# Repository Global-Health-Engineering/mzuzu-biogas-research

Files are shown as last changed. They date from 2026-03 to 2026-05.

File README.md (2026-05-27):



# Solar Sludge Pasteurization Control System

This repository contains the engineering files, firmware, and analysis scripts for a solar-powered sludge pasteurization system deployed in Mzuzu, Malawi. The system automates the thermal treatment of anaerobic digester effluent to ensure safe, pathogen-free discharge.

## Electronics Design
Hardware design files developed in KiCad.
- solar_pasteurization_controller: The main PCB project including schematics (mcu, power, solar_charger, actuators), PCB layout, and 3D models.
- simulations: SPICE simulations for the power switching circuitry.

## Microcontroller Software
Primary system firmware built using Zephyr RTOS.
- nucleo_l432kc_program_ert_algo: The production firmware implementing the retention time estimation algorithm. Needs to be tested.
- LoRa_TX / LoRa_RX: Simple LoRa scripts for testing. LoRa RX runs on the STM32L432KC eval-board that is connected to the research hut laptop.
- nucleo_l432kc_program_no_rtc: The production firmware implementing the threshold-based control logic.

## Arduino Software
Software that runs on the 2 Arduinos inside the Mzuzu research hut.
- luca_electronics: The software that runs on the microcontroller that's part of Luca Jakobs' biogas pasteurizer system.
- shared_plumbing_electronics: This pertains to the infrastructure electronics.

## Measurements
Data processing and experimental analysis scripts (Python).
- Heat Exchanger Efficiency: Scripts to calculate the h values and thermal efficiency from raw .csv data.
- espinosa_d_values: Logarithmic fit scripts for pathogen inactivation kinetics with data points taken from Deniz Cinar's paper.
- solcast_data_analysis: Analysis of solar irradiance data for the Mzuzu region.
- data_analysis_scripts: Contains the Python scripts for analyzing the .csv data files that can be found in the mzuzu-biogas-research git repo. That repo contains up-to-date data from the research site. 

## PC Software
High-level data handling and parsing for the research hut PC.
- nucleo_parser: Parses the USB packets sent by the LoRa RX microcontroller.
- edb_parser: Parses the USB packets sent by the infrastructure microcontroller. This is called *edb_parser* because it evolved from a simple automation of the EDB (effluent distribution) box.
- lj_parser: Parses the USB packets sent by the biogas pasteurization system microcontroller

For questions, please contact me through:
rcppolat@gmail.com

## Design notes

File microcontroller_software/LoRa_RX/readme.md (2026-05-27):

This is the piece of code that runs on the LoRa board located inside the research hut.
It receives LoRa packets from the solar heater, parses them, and sends them as a 
serial packet to the research hut computer over USB.

This is a Zephyr project.

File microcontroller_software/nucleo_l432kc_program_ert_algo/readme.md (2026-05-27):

This is the code that runs on the solar heater (ert calculating algorithm).
You need a local Zephyr RTOS installation to build and flash this code.

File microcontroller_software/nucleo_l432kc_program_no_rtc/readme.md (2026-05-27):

This is the code that runs on the solar heater (naive algorithm).
You need a local Zephyr RTOS installation to build and flash this code.

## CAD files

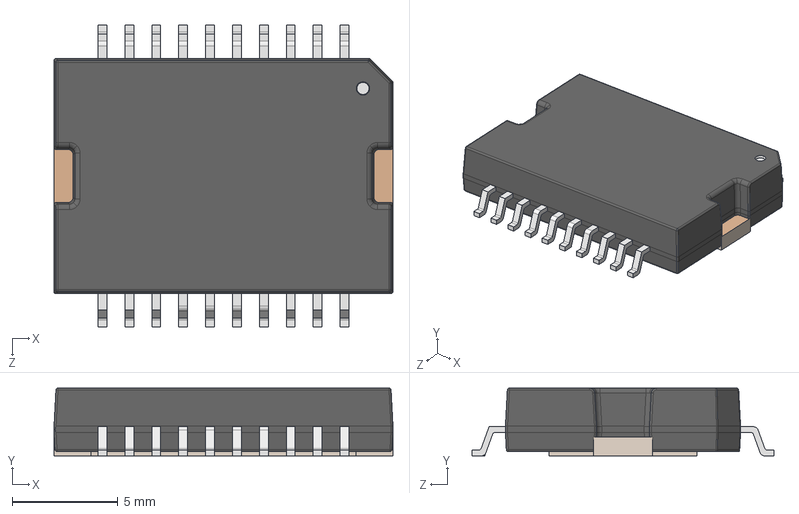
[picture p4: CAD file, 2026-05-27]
Electronics Design/solar_pasteurization_controller/User Library-HSOP_20pin_IC-MC33886PVW.step
16.0 x 3.20 x 14.2 mm

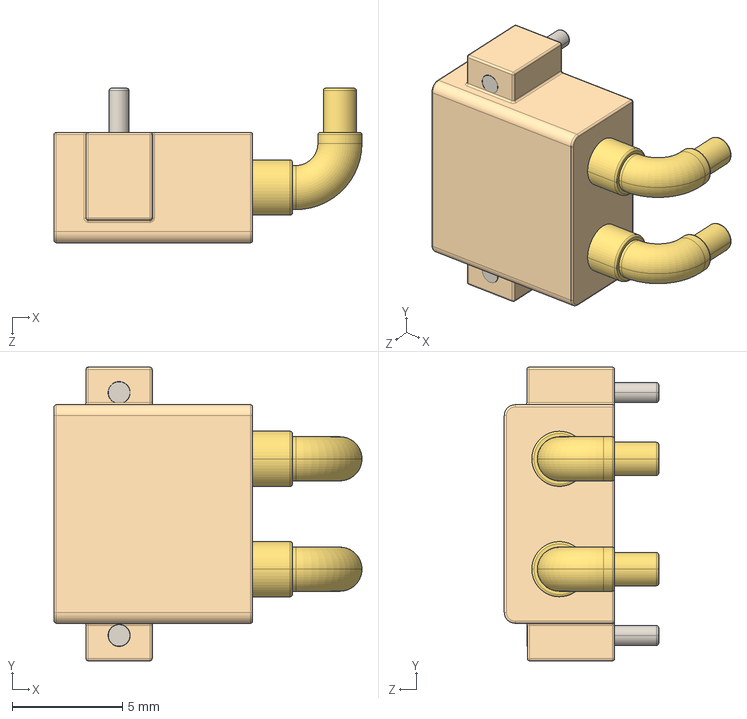
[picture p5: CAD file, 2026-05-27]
Electronics Design/solar_pasteurization_controller/User Library-XT30PW-M.step
13.9 x 13.3 x 7.00 mm

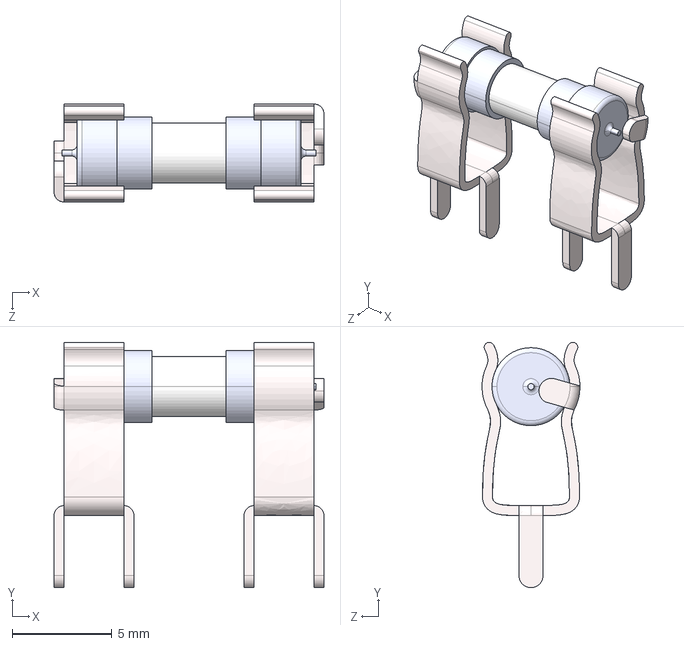
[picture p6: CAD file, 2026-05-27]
Electronics Design/solar_pasteurization_controller/Fuse Holder PCB.STEP
13.5 x 12.3 x 4.90 mm

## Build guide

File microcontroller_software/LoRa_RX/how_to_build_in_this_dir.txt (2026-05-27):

source ~/zephyrproject/.venv/bin/activate
source ~/zephyrproject/zephyr/zephyr-env.sh

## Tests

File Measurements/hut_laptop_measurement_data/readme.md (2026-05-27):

# Research Hut Data Logs

The research computer in the Mzuzu Research Hut records data from two independent microcontroller systems:

1. **Solar heater telemetry** (received over LoRa)
2. **Infrastructure / EDB monitoring data** (received directly over USB)

Each system produces a separate daily log file.

---

## Solar Heater Telemetry Logs

**Filename format:**  
`nucleo_data_YYYY-MM-DD`

Example:  
`nucleo_data_2026-03-25`

### Overview

The research hut computer is connected to a **LoRa receiver microcontroller**. This receiver collects telemetry packets transmitted by the **solar heater microcontroller**.

When a packet is received:

1. The LoRa receiver parses the telemetry data.
2. The parsed data is sent to the research hut computer via USB.
3. The research hut computer timestamps and stores the data in the daily log file.

### Data fields

| Field | Description |
|---|---|
| `timestamp` | Time the packet was received by the research hut computer |
| `battery_mv` | Battery voltage (mV) measured when the solar heater microcontroller woke up |
| `die_temp_c` | Internal microcontroller temperature (°C) at wake-up |
| `tank_top_c` | Water temperature at the top of the tank (°C) at wake-up |
| `tank_temp_start_c` | Water temperature in the middle of the tank (°C) at wake-up |
| `tank_temp_bottom_c` | Water temperature at the bottom of the tank (°C) at wake-up |
| `tank_temp_end_c` | Water temperature in the middle of the tank (°C) measured before sleep |

---

## Infrastructure / EDB Logs

**Filename format:**  
`edb_data_YYYY-MM-DD`

Example:  
`edb_data_2026-03-14`

### Overview

The research hut computer is connected directly to the **infrastructure electronics microcontroller**.

This controller automates site infrastructure and gathers measurements from connected sensors. Measurements are transmitted to the research hut computer over USB, where they are parsed, timestamped, and saved.

### Data fields

| Field | Description |
|---|---|
| `timestamp` | Time the measurement packet was received by the research hut computer |
| `edb_drain_state` | EDB drain pump state (`0` = off, `1` = on) |
| `edb_effluent_state` | EDB effluent pump state (`0` = off, `1` = on) |
| `tank_level` | Effluent tank fill level, ranging from `0` to `1023` |
| `flow_rate` | Flow sensor output. Until **2026-03-10**, this value represented raw pulse counts. From **2026-03-10 onward**, it represents flow rate in **L/min** |

---

## Notes

- All timestamps correspond to **when data was received and recorded by the research hut computer**, not necessarily when the measurement was taken.
- Each file contains one day's worth of logged data.
- Field names are preserved exactly as written in the data logs.

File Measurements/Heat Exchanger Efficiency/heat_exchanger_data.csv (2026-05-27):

exit out | exit in | input out | input in
33.437500 | 31.312500 | 24.812500 | 24.0
33.312500 | 31.125000 | 24.812500 | 24.0
33.187500 | 30.937500 | 24.875000 | 24.0
32.687500 | 31.125000 | 24.875000 | 24.0
31.937500 | 31.937500 | 24.875000 | 24.0
31.250000 | 33.187500 | 24.937500 | 24.0
30.750000 | 34.812500 | 25.000000 | 24.0
30.437500 | 36.750000 | 25.125000 | 24.0
30.437500 | 39.000000 | 25.250000 | 24.0
30.562500 | 41.562500 | 25.500000 | 24.0
31.000000 | 44.312500 | 25.812500 | 24.0
31.562500 | 47.125000 | 26.125000 | 24.0
32.375000 | 49.875000 | 26.562500 | 24.0
33.312500 | 52.500000 | 27.000000 | 24.0
34.500000 | 54.937500 | 27.500000 | 24.0
35.875000 | 57.250000 | 28.000000 | 24.0
37.375000 | 59.312500 | 28.500000 | 24.0
38.875000 | 61.250000 | 29.000000 | 24.0
40.375000 | 62.937500 | 29.437500 | 24.0
42.000000 | 64.500000 | 29.875000 | 24.0
43.500000 | 65.937500 | 30.250000 | 24.0
44.937500 | 67.125000 | 30.625000 | 24.0
46.375000 | 68.312500 | 31.062500 | 24.0
47.812500 | 69.312500 | 31.500000 | 24.0
49.250000 | 70.250000 | 31.875000 | 24.0
50.562500 | 71.062500 | 32.312500 | 24.0
51.687500 | 71.875000 | 32.687500 | 24.0
52.687500 | 72.562500 | 33.000000 | 24.0
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

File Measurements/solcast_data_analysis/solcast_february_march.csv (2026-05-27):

air_temp | dni | ghi | period_end | period
18 | 0 | 0 | 2026-02-01T00:05:00+00:00 | PT5M
18 | 0 | 0 | 2026-02-01T00:10:00+00:00 | PT5M
18 | 0 | 0 | 2026-02-01T00:15:00+00:00 | PT5M
18 | 0 | 0 | 2026-02-01T00:20:00+00:00 | PT5M
18 | 0 | 0 | 2026-02-01T00:25:00+00:00 | PT5M
18 | 0 | 0 | 2026-02-01T00:30:00+00:00 | PT5M
18 | 0 | 0 | 2026-02-01T00:35:00+00:00 | PT5M
18 | 0 | 0 | 2026-02-01T00:40:00+00:00 | PT5M
18 | 0 | 0 | 2026-02-01T00:45:00+00:00 | PT5M
18 | 0 | 0 | 2026-02-01T00:50:00+00:00 | PT5M
18 | 0 | 0 | 2026-02-01T00:55:00+00:00 | PT5M
18 | 0 | 0 | 2026-02-01T01:00:00+00:00 | PT5M
18 | 0 | 0 | 2026-02-01T01:05:00+00:00 | PT5M
18 | 0 | 0 | 2026-02-01T01:10:00+00:00 | PT5M
18 | 0 | 0 | 2026-02-01T01:15:00+00:00 | PT5M
18 | 0 | 0 | 2026-02-01T01:20:00+00:00 | PT5M
18 | 0 | 0 | 2026-02-01T01:25:00+00:00 | PT5M
18 | 0 | 0 | 2026-02-01T01:30:00+00:00 | PT5M
18 | 0 | 0 | 2026-02-01T01:35:00+00:00 | PT5M
18 | 0 | 0 | 2026-02-01T01:40:00+00:00 | PT5M
18 | 0 | 0 | 2026-02-01T01:45:00+00:00 | PT5M
18 | 0 | 0 | 2026-02-01T01:50:00+00:00 | PT5M
18 | 0 | 0 | 2026-02-01T01:55:00+00:00 | PT5M
18 | 0 | 0 | 2026-02-01T02:00:00+00:00 | PT5M
18 | 0 | 0 | 2026-02-01T02:05:00+00:00 | PT5M
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

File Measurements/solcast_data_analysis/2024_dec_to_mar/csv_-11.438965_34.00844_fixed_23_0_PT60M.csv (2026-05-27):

air_temp | dni | ghi | precipitation_rate | period_end | period
17 | 0 | 0 | 0.8 | 2024-12-01T01:00:00+00:00 | PT60M
18 | 0 | 0 | 0.8 | 2024-12-01T02:00:00+00:00 | PT60M
18 | 0 | 0 | 0.8 | 2024-12-01T03:00:00+00:00 | PT60M
18 | 25 | 28 | 0.8 | 2024-12-01T04:00:00+00:00 | PT60M
18 | 0 | 82 | 0.7 | 2024-12-01T05:00:00+00:00 | PT60M
18 | 0 | 153 | 1.6 | 2024-12-01T06:00:00+00:00 | PT60M
19 | 0 | 212 | 0.3 | 2024-12-01T07:00:00+00:00 | PT60M
19 | 0 | 237 | 0.5 | 2024-12-01T08:00:00+00:00 | PT60M
19 | 0 | 239 | 0.4 | 2024-12-01T09:00:00+00:00 | PT60M
20 | 0 | 218 | 1.3 | 2024-12-01T10:00:00+00:00 | PT60M
21 | 0 | 327 | 0.5 | 2024-12-01T11:00:00+00:00 | PT60M
21 | 0 | 269 | 0.8 | 2024-12-01T12:00:00+00:00 | PT60M
21 | 0 | 332 | 0.6 | 2024-12-01T13:00:00+00:00 | PT60M
21 | 0 | 174 | 0.2 | 2024-12-01T14:00:00+00:00 | PT60M
21 | 0 | 73 | 0 | 2024-12-01T15:00:00+00:00 | PT60M
21 | 0 | 28 | 0 | 2024-12-01T16:00:00+00:00 | PT60M
20 | 0 | 0 | 0.1 | 2024-12-01T17:00:00+00:00 | PT60M
20 | 0 | 0 | 0.2 | 2024-12-01T18:00:00+00:00 | PT60M
20 | 0 | 0 | 0.1 | 2024-12-01T19:00:00+00:00 | PT60M
20 | 0 | 0 | 0 | 2024-12-01T20:00:00+00:00 | PT60M
20 | 0 | 0 | 0 | 2024-12-01T21:00:00+00:00 | PT60M
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

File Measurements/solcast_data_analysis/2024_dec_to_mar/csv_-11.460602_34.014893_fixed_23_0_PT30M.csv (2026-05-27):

air_temp | dni | ghi | period_end | period
18 | 0 | 0 | 2026-03-01T00:30:00+00:00 | PT30M
18 | 0 | 0 | 2026-03-01T01:00:00+00:00 | PT30M
18 | 0 | 0 | 2026-03-01T01:30:00+00:00 | PT30M
18 | 0 | 0 | 2026-03-01T02:00:00+00:00 | PT30M
18 | 0 | 0 | 2026-03-01T02:30:00+00:00 | PT30M
18 | 0 | 0 | 2026-03-01T03:00:00+00:00 | PT30M
18 | 0 | 0 | 2026-03-01T03:30:00+00:00 | PT30M
18 | 0 | 1 | 2026-03-01T04:00:00+00:00 | PT30M
19 | 0 | 31 | 2026-03-01T04:30:00+00:00 | PT30M
19 | 0 | 91 | 2026-03-01T05:00:00+00:00 | PT30M
19 | 0 | 143 | 2026-03-01T05:30:00+00:00 | PT30M
19 | 0 | 236 | 2026-03-01T06:00:00+00:00 | PT30M
20 | 22 | 331 | 2026-03-01T06:30:00+00:00 | PT30M
20 | 60 | 415 | 2026-03-01T07:00:00+00:00 | PT30M
20 | 0 | 185 | 2026-03-01T07:30:00+00:00 | PT30M
21 | 0 | 125 | 2026-03-01T08:00:00+00:00 | PT30M
21 | 26 | 468 | 2026-03-01T08:30:00+00:00 | PT30M
21 | 100 | 629 | 2026-03-01T09:00:00+00:00 | PT30M
21 | 308 | 764 | 2026-03-01T09:30:00+00:00 | PT30M
22 | 228 | 735 | 2026-03-01T10:00:00+00:00 | PT30M
23 | 160 | 690 | 2026-03-01T10:30:00+00:00 | PT30M
23 | 0 | 561 | 2026-03-01T11:00:00+00:00 | PT30M
23 | 0 | 455 | 2026-03-01T11:30:00+00:00 | PT30M
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

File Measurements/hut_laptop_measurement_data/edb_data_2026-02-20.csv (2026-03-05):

timestamp | edb_drain_state | edb_effluent_state | tank_level | flow_rate
2026-02-20T10:20:50.530655 | 0 | 1 | 570 | 258.0
2026-02-20T10:21:43.362830 | 0 | 1 | 569 | 0.0
2026-02-20T10:22:16.362038 | 0 | 1 | 569 | 271.0
2026-02-20T10:22:29.886086 | 0 | 1 | 569 | 264.0
2026-02-20T10:22:45.812798 | 0 | 1 | 569 | 272.0
2026-02-20T10:22:59.373170 | 0 | 1 | 570 | 0.0
2026-02-20T10:24:24.214318 | 0 | 1 | 569 | 0.0
2026-02-20T10:24:25.223619 | 0 | 1 | 569 | 0.0
2026-02-20T10:24:26.234812 | 0 | 1 | 569 | 0.0
2026-02-20T10:24:27.244632 | 0 | 1 | 570 | 0.0
2026-02-20T10:24:28.255600 | 0 | 1 | 573 | 0.0
2026-02-20T10:24:29.265635 | 0 | 1 | 569 | 0.0
2026-02-20T10:24:30.275482 | 0 | 1 | 570 | 0.0
2026-02-20T10:24:31.281476 | 0 | 1 | 569 | 0.0
2026-02-20T10:24:32.293637 | 0 | 1 | 570 | 0.0
2026-02-20T10:24:33.296660 | 0 | 1 | 570 | 0.0
2026-02-20T10:24:34.307531 | 0 | 1 | 569 | 0.0
2026-02-20T10:24:35.312516 | 0 | 1 | 569 | 0.0
2026-02-20T10:24:36.323608 | 0 | 1 | 571 | 0.0
2026-02-20T10:24:37.333398 | 0 | 1 | 570 | 0.0
2026-02-20T10:24:38.344312 | 0 | 1 | 569 | 0.0
2026-02-20T10:24:39.354387 | 0 | 1 | 569 | 0.0
2026-02-20T10:24:40.364271 | 0 | 1 | 569 | 0.0
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

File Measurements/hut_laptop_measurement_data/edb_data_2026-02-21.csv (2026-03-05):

timestamp | edb_drain_state | edb_effluent_state | tank_level | flow_rate
2026-02-21T00:00:00.975584 | 0 | 1 | 550 | 0.0
2026-02-21T00:00:01.985707 | 0 | 1 | 550 | 0.0
2026-02-21T00:00:02.993092 | 0 | 1 | 552 | 0.0
2026-02-21T00:00:04.001569 | 0 | 1 | 550 | 0.0
2026-02-21T00:00:05.011532 | 0 | 1 | 550 | 0.0
2026-02-21T00:00:06.015497 | 0 | 1 | 550 | 0.0
2026-02-21T00:00:07.026484 | 0 | 1 | 550 | 0.0
2026-02-21T00:00:08.032509 | 0 | 1 | 550 | 0.0
2026-02-21T00:00:09.042461 | 0 | 1 | 550 | 0.0
2026-02-21T00:00:10.053462 | 0 | 1 | 550 | 0.0
2026-02-21T00:00:11.064472 | 0 | 1 | 551 | 0.0
2026-02-21T00:00:12.074427 | 0 | 1 | 551 | 0.0
2026-02-21T00:00:13.084393 | 0 | 1 | 550 | 0.0
2026-02-21T00:00:14.090350 | 0 | 1 | 550 | 0.0
2026-02-21T00:00:15.099490 | 0 | 1 | 550 | 0.0
2026-02-21T00:00:16.106267 | 0 | 1 | 550 | 0.0
2026-02-21T00:00:17.116411 | 0 | 1 | 550 | 0.0
2026-02-21T00:00:18.126308 | 0 | 1 | 550 | 0.0
2026-02-21T00:00:19.137369 | 0 | 1 | 550 | 0.0
2026-02-21T00:00:20.147367 | 0 | 1 | 550 | 0.0
2026-02-21T00:00:21.157421 | 0 | 1 | 550 | 0.0
2026-02-21T00:00:22.168365 | 0 | 1 | 550 | 0.0
2026-02-21T00:00:23.179398 | 0 | 1 | 550 | 0.0
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

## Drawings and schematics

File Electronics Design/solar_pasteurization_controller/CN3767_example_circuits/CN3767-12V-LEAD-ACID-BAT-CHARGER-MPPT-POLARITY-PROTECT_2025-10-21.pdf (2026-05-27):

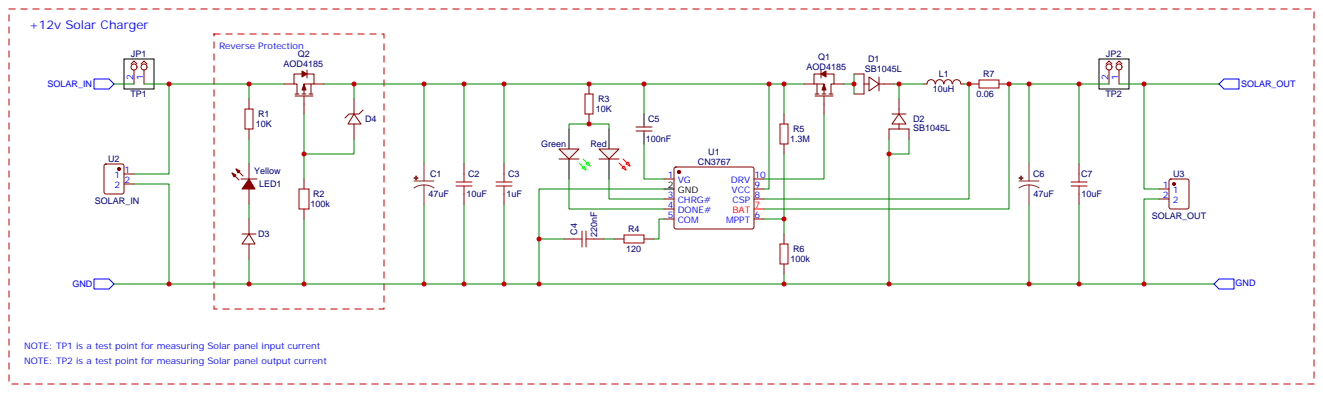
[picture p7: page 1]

NOTE: TP1 is a test point for measuring Solar panel input current
NOTE: TP2 is a test point for measuring Solar panel output current

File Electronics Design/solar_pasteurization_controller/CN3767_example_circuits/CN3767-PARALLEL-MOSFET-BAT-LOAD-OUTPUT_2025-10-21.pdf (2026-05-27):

# Ichg = 0.12 / Rcs

# BAT

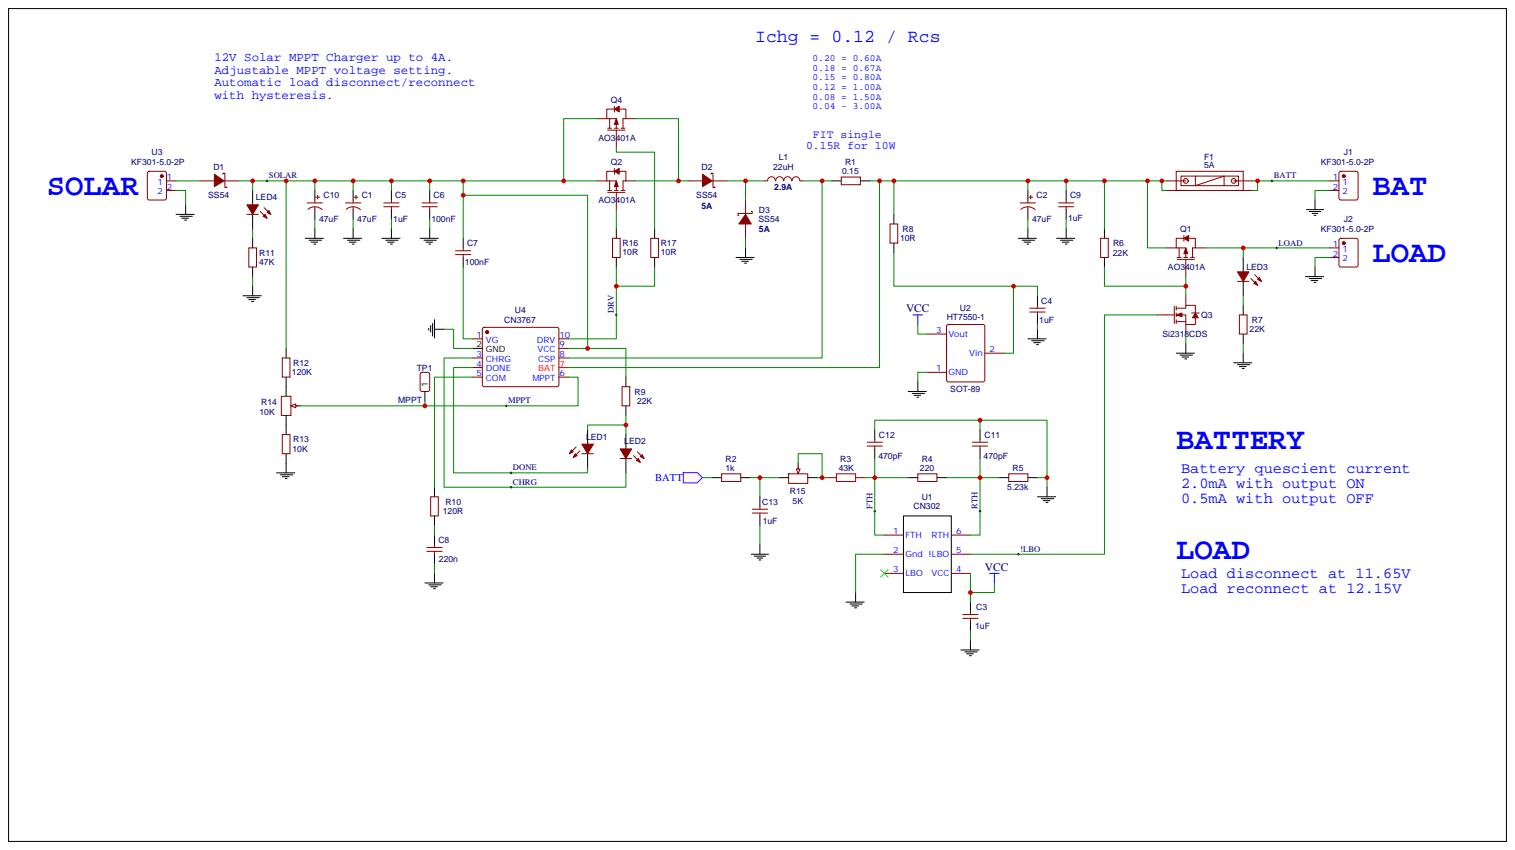
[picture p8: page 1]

12V Solar MPPT Charger up to 4A.
Adjustable MPPT voltage setting.
Automatic load disconnect/reconnect
with hysteresis.

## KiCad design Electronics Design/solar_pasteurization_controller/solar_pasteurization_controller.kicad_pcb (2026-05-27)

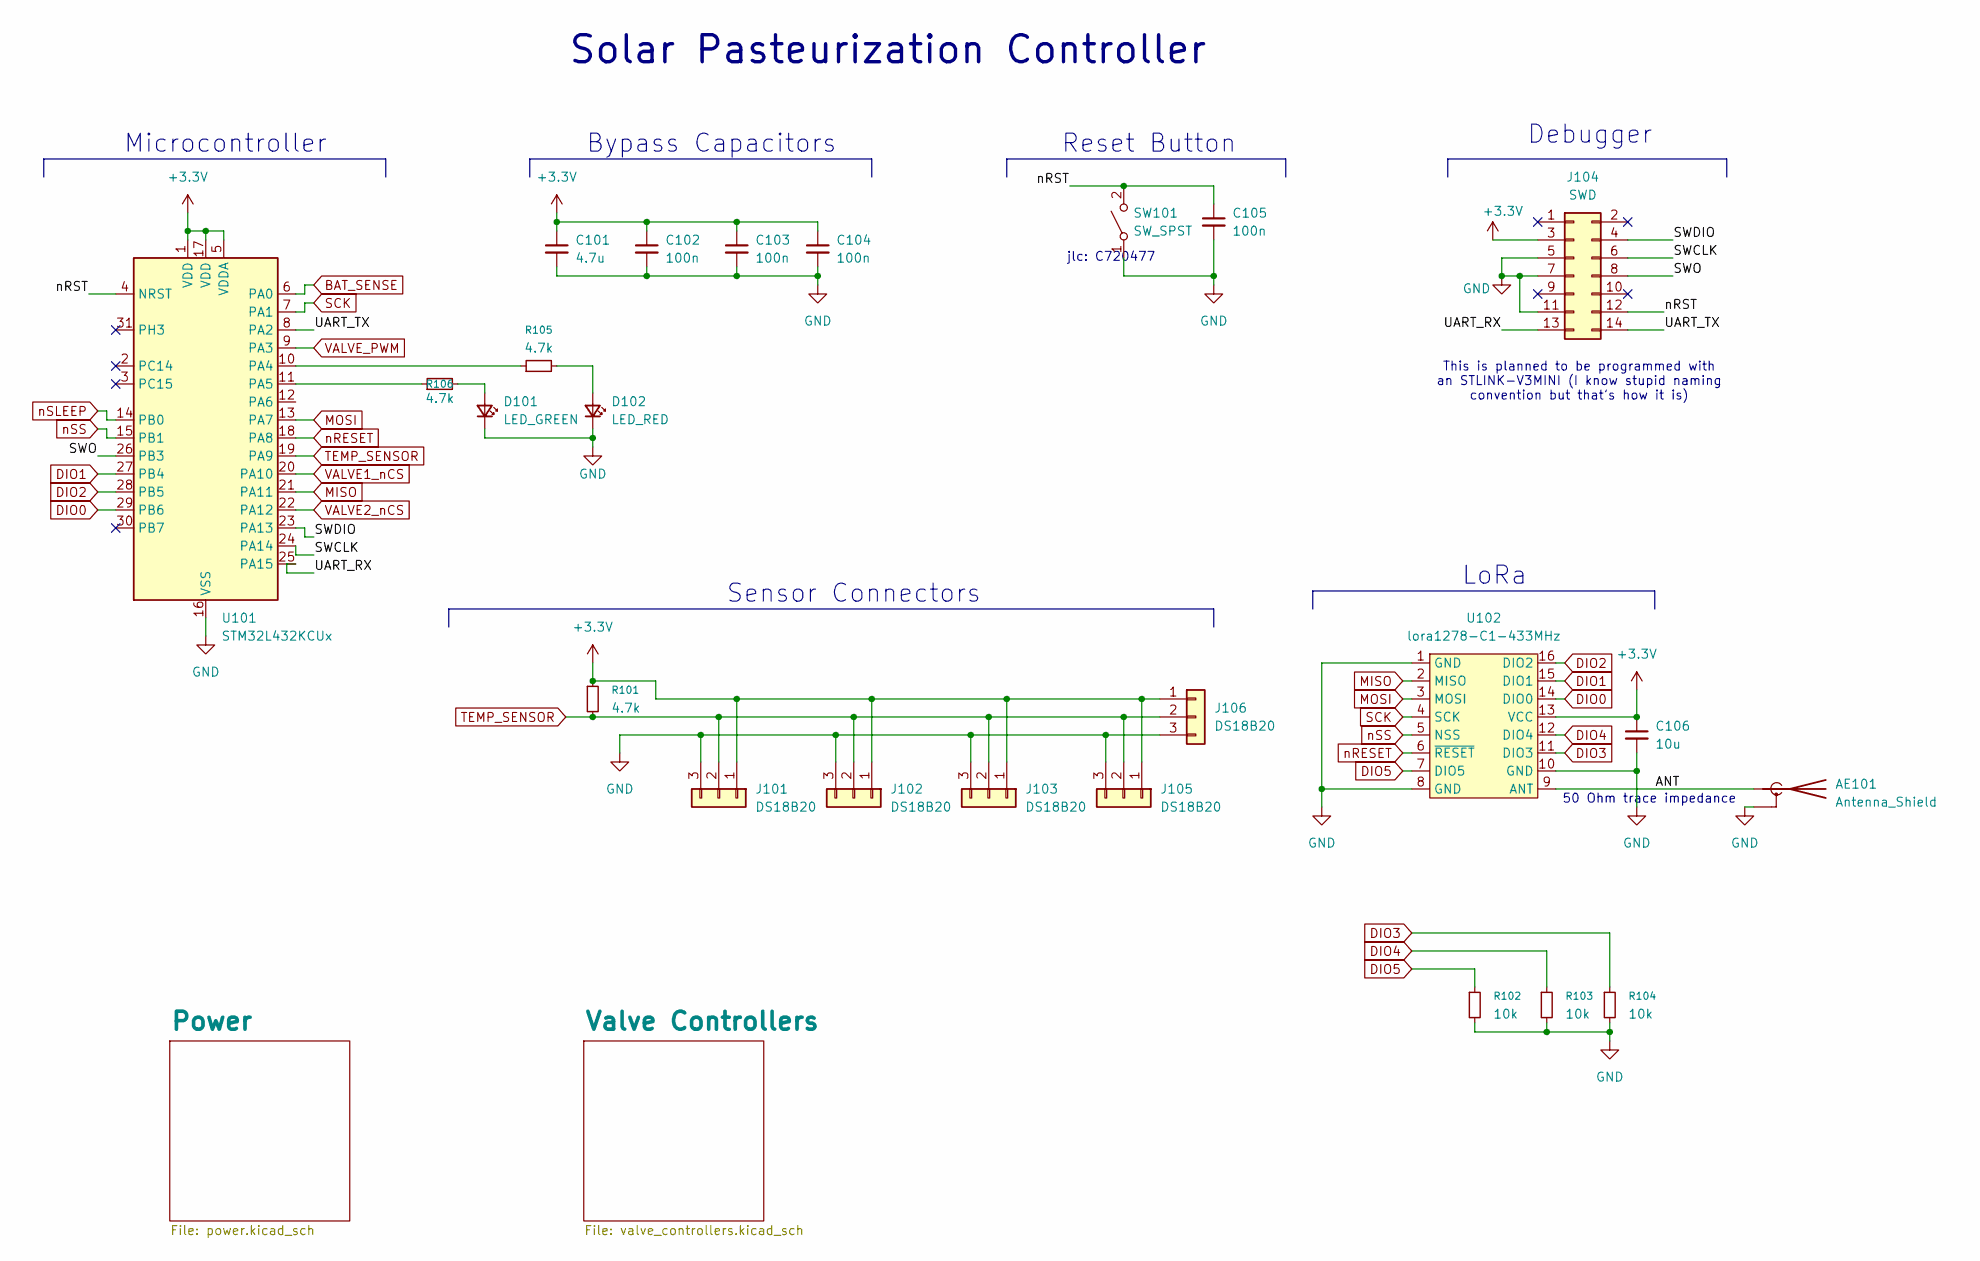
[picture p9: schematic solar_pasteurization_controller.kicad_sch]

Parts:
AE101: Antenna_Shield; SMA_Samtec_SMA-J-P-H-ST-EM1_EdgeMount; JLCPCB Part # C5301850
C101: 4.7u; C_0603_1608Metric; JLCPCB Part # C19666
C102, C103, C104, C105: 100n; C_0603_1608Metric; JLCPCB Part # C14663
C106: 10u; C_0603_1608Metric; JLCPCB Part # C96446
D101: LED_GREEN; LED_0805_2012Metric; JLCPCB Part # C2297
D102: LED_RED; LED_0805_2012Metric; JLCPCB Part # C84256
J101, J102, J103, J105, J106: DS18B20; Molex_PicoBlade_53048-0310_1x03_P1.25mm_Horizontal; JLCPCB Part # C505275
J104: SWD; PinHeader_2x07_P1.27mm_Vertical; JLCPCB Part # C2935955
R101, R105, R106: 4.7k; R_0603_1608Metric; JLCPCB Part # C23162
R102, R103, R104: 10k; R_0603_1608Metric; JLCPCB Part # C25804
SW101: SW_SPST; SW_SPST_TS-1088-xR025; JLCPCB Part # C720477
U101: STM32L432KCUx; QFN-32-1EP_5x5mm_P0.5mm_EP3.45x3.45mm; JLCPCB Part # C1337280
U102: lora1278-C1-433MHz; JLCPCB Part # C3001529

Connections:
+3.3V: C101.1, C102.1, C103.1, C104.1, C106.1, J101.1, J102.1, J103.1, J104.3, J105.1, J106.1, R101.1, U101.1 (VDD), U101.5 (VDDA), U101.17 (VDD), U102.13 (VCC); also elsewhere on the board
/ANT: AE101.1 (A), U102.9 (ANT)
/SWCLK: J104.6, U101.24 (PA14)
/SWDIO: J104.4, U101.23 (PA13)
/SWO: J104.8, U101.26 (PB3)
/UART_RX: J104.13, U101.25 (PA15)
/UART_TX: J104.14, U101.8 (PA2)
/nRST: C105.1, J104.12, SW101.2 (B), U101.4 (NRST)
BAT_SENSE: U101.6 (PA0); also elsewhere on the board
DIO0: U101.29 (PB6), U102.14 (DIO0)
DIO1: U101.27 (PB4), U102.15 (DIO1)
DIO2: U101.28 (PB5), U102.16 (DIO2)
DIO3: R104.1, U102.11 (DIO3)
DIO4: R103.1, U102.12 (DIO4)
DIO5: R102.1, U102.7 (DIO5)
GND: AE101.2 (Shield), C101.2, C102.2, C103.2, C104.2, C105.2, C106.2, D101.1 (K), D102.1 (K), J101.3, J102.3, J103.3, J104.5, J104.7, J104.11, J105.3, J106.3, R102.2, R103.2, R104.2, SW101.1 (A), U101.16 (VSS), U101.32 (VSS), U101.33 (VSS), U102.1 (GND), U102.8 (GND), U102.10 (GND); also elsewhere on the board
MISO: U101.21 (PA11), U102.2 (MISO); also elsewhere on the board
MOSI: U101.13 (PA7), U102.3 (MOSI); also elsewhere on the board
unnamed: D101.2 (A), R106.2
unnamed: D102.2 (A), R105.2
unnamed: R105.1, U101.10 (PA4)
unnamed: R106.1, U101.11 (PA5)
SCK: U101.7 (PA1), U102.4 (SCK); also elsewhere on the board
TEMP_SENSOR: J101.2, J102.2, J103.2, J105.2, J106.2, R101.2, U101.19 (PA9)
VALVE1_nCS: U101.20 (PA10); also elsewhere on the board
VALVE2_nCS: U101.22 (PA12); also elsewhere on the board
VALVE_PWM: U101.9 (PA3); also elsewhere on the board
nRESET: U101.18 (PA8), U102.6 (~RESET)
nSLEEP: U101.14 (PB0); also elsewhere on the board
nSS: U101.15 (PB1), U102.5 (NSS)

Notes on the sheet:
50 Ohm trace impedance
Microcontroller
Sensor Connectors
Debugger
Reset Button
Bypass Capacitors
This is planned to be programmed with an STLINK-V3MINI (I know stupid naming convention but that's how it is)
Solar Pasteurization Controller
LoRa
jlc: C720477

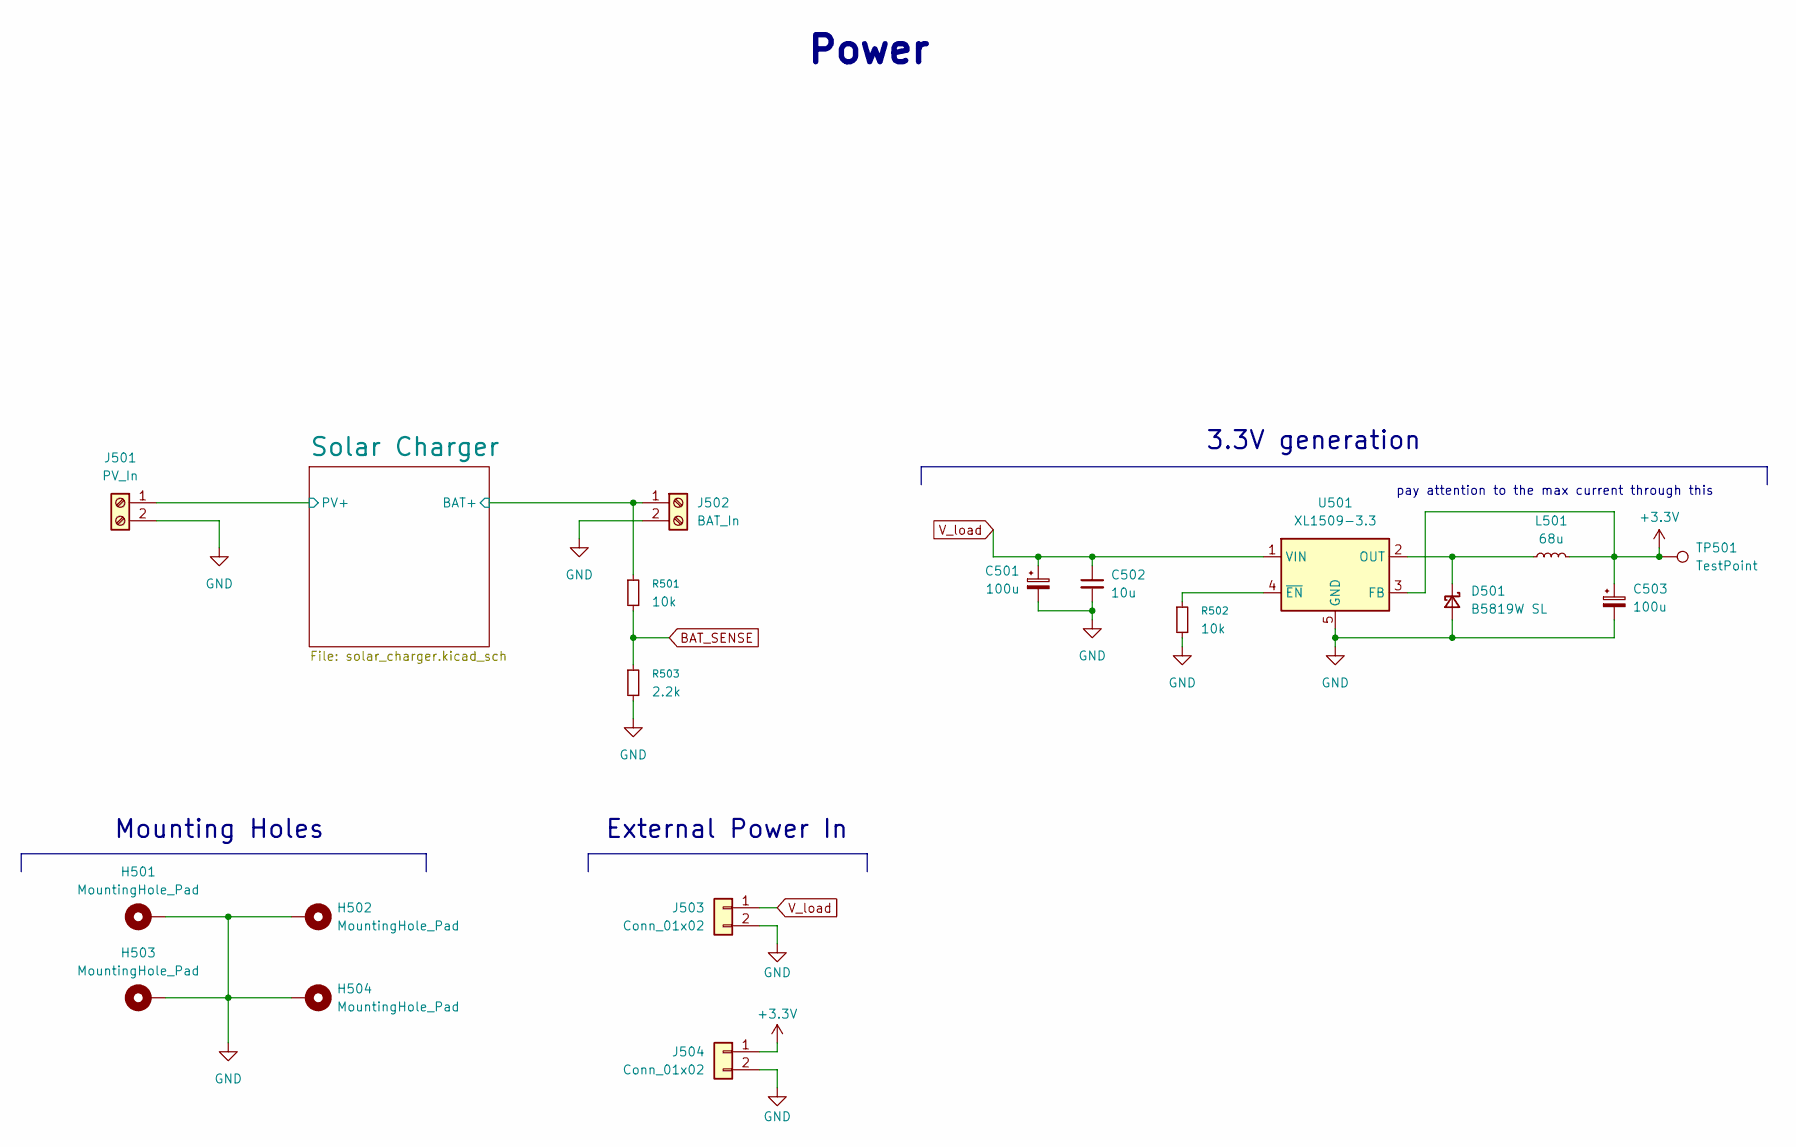
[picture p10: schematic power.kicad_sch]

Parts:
C501, C503: 100u; CP_Elec_6.3x5.9; LCSC_Part_Number C136277
C502: 10u; C_0603_1608Metric; LCSC_Part_Number C15525
D501: B5819W SL; D_SOD-123; LCSC_Part_Number C146713
H501, H502, H503, H504: MountingHole_Pad; MountingHole_2.7mm_M2.5_DIN965_Pad_TopBottom
J501: PV_In; AMASS_XT30PW-M_1x02_P2.50mm_Horizontal; JLCPCB Part # C431092
J502: BAT_In; AMASS_XT30PW-M_1x02_P2.50mm_Horizontal; JLCPCB Part # C431092
J503, J504: Conn_01x02; PinHeader_1x02_P2.54mm_Vertical
L501: 68u; L_Changjiang_FNR5040S; LCSC_Part_Number C167977
R501, R502: 10k; R_0603_1608Metric; LCSC_Part_Number C190095
R503: 2.2k; R_0603_1608Metric; JLCPCB Part # C4190
TP501: TestPoint; TestPoint_Pad_1.5x1.5mm
U501: XL1509-3.3; SOIC-8_3.9x4.9mm_P1.27mm; LCSC_Part_Number C2681226

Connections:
+3.3V: C503.1, J504.1, L501.2, TP501.1, U501.3 (FB); also elsewhere on the board
/Power/Solar Charger/PV+: J501.1; also elsewhere on the board
/Power/Solar Charger/V_bat: J502.1, R501.1; also elsewhere on the board
BAT_SENSE: R501.2, R503.1; also elsewhere on the board
GND: C501.2, C502.2, C503.2, D501.2 (A), H501.1, H502.1, H503.1, H504.1, J501.2, J502.2, J503.2, J504.2, R502.2, R503.2, U501.5 (GND), U501.6 (GND), U501.7 (GND), U501.8 (GND); also elsewhere on the board
unnamed: D501.1 (K), L501.1, U501.2 (OUT)
unnamed: R502.1, U501.4 (~EN)
V_load: C501.1, C502.1, J503.1, U501.1 (VIN); also elsewhere on the board

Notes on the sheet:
Power
External Power In
Mounting Holes
3.3V generation
pay attention to the max current through this

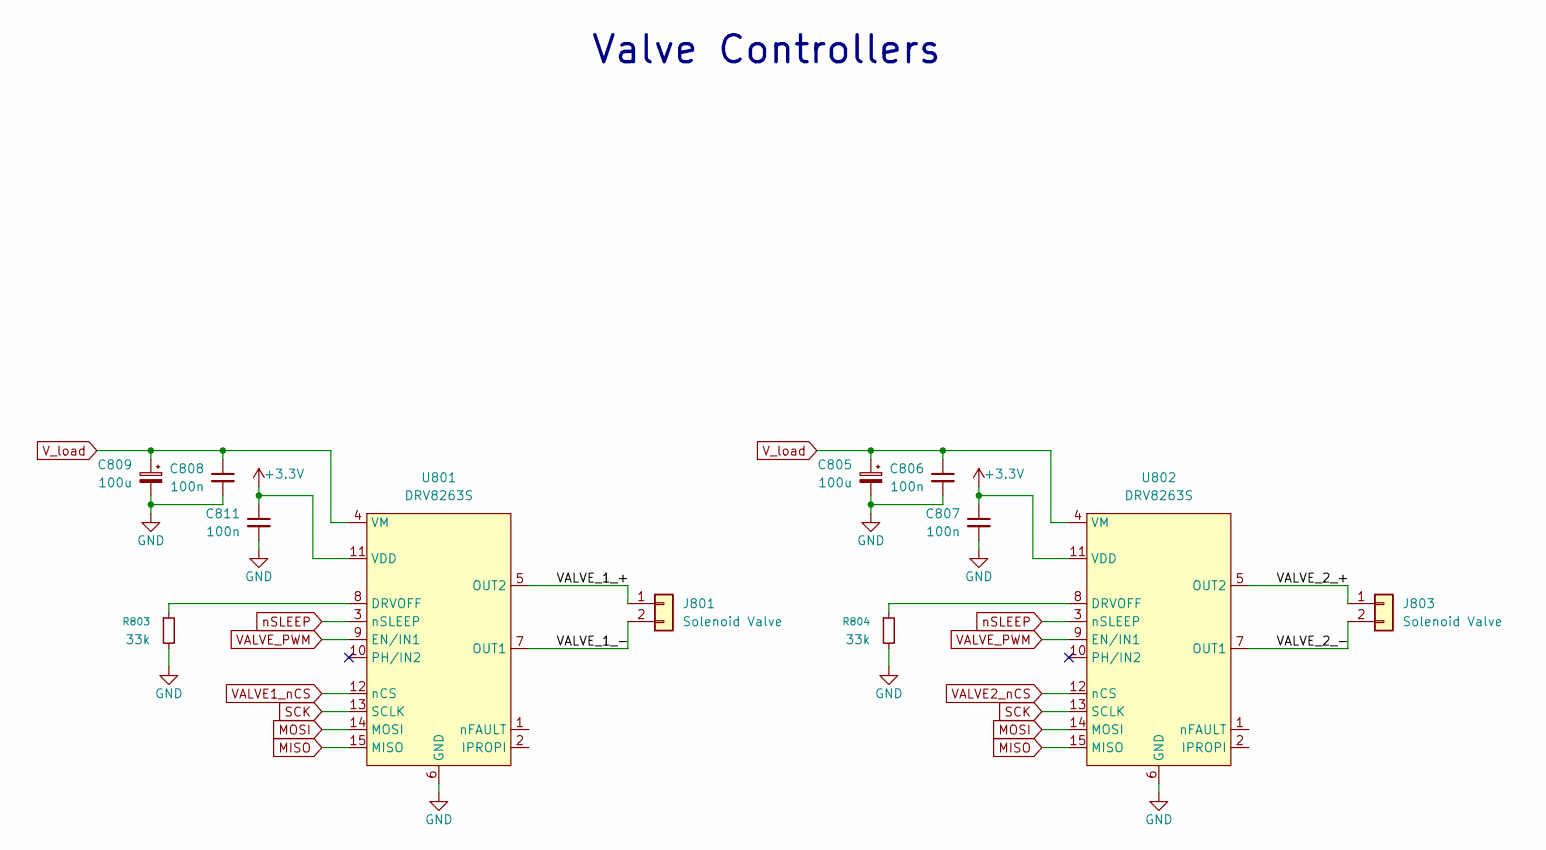
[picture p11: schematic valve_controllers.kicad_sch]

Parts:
C805, C809: 100u; CP_Elec_6.3x5.9; JLCPCB Part # C72478
C806, C807, C808, C811: 100n; C_0603_1608Metric; JLCPCB Part # C14663
J801, J803: Solenoid Valve; AMASS_XT30PW-M_1x02_P2.50mm_Horizontal; JLCPCB Part # C431092
R803, R804: 33k; R_0603_1608Metric; JLCPCB Part # C4216
U801, U802: DRV8263S; JLCPCB Part # C51893863

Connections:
+3.3V: C807.1, C811.1, U801.11 (VDD), U802.11 (VDD); also elsewhere on the board
/Valve Controllers/VALVE_1_+: J801.1, U801.5 (OUT2)
/Valve Controllers/VALVE_1_-: J801.2, U801.7 (OUT1)
/Valve Controllers/VALVE_2_+: J803.1, U802.5 (OUT2)
/Valve Controllers/VALVE_2_-: J803.2, U802.7 (OUT1)
GND: C805.2, C806.2, C807.2, C808.2, C809.2, C811.2, R803.2, R804.2, U801.6 (GND), U802.6 (GND); also elsewhere on the board
MISO: U801.15 (MISO), U802.15 (MISO); also elsewhere on the board
MOSI: U801.14 (MOSI), U802.14 (MOSI); also elsewhere on the board
unnamed: R803.1, U801.8 (DRVOFF)
unnamed: R804.1, U802.8 (DRVOFF)
SCK: U801.13 (SCLK), U802.13 (SCLK); also elsewhere on the board
VALVE1_nCS: U801.12 (nCS); also elsewhere on the board
VALVE2_nCS: U802.12 (nCS); also elsewhere on the board
VALVE_PWM: U801.9 (EN/IN1), U802.9 (EN/IN1); also elsewhere on the board
V_load: C805.1, C806.1, C808.1, C809.1, U801.4 (VM), U802.4 (VM); also elsewhere on the board
nSLEEP: U801.3 (nSLEEP), U802.3 (nSLEEP); also elsewhere on the board

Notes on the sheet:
Valve Controllers

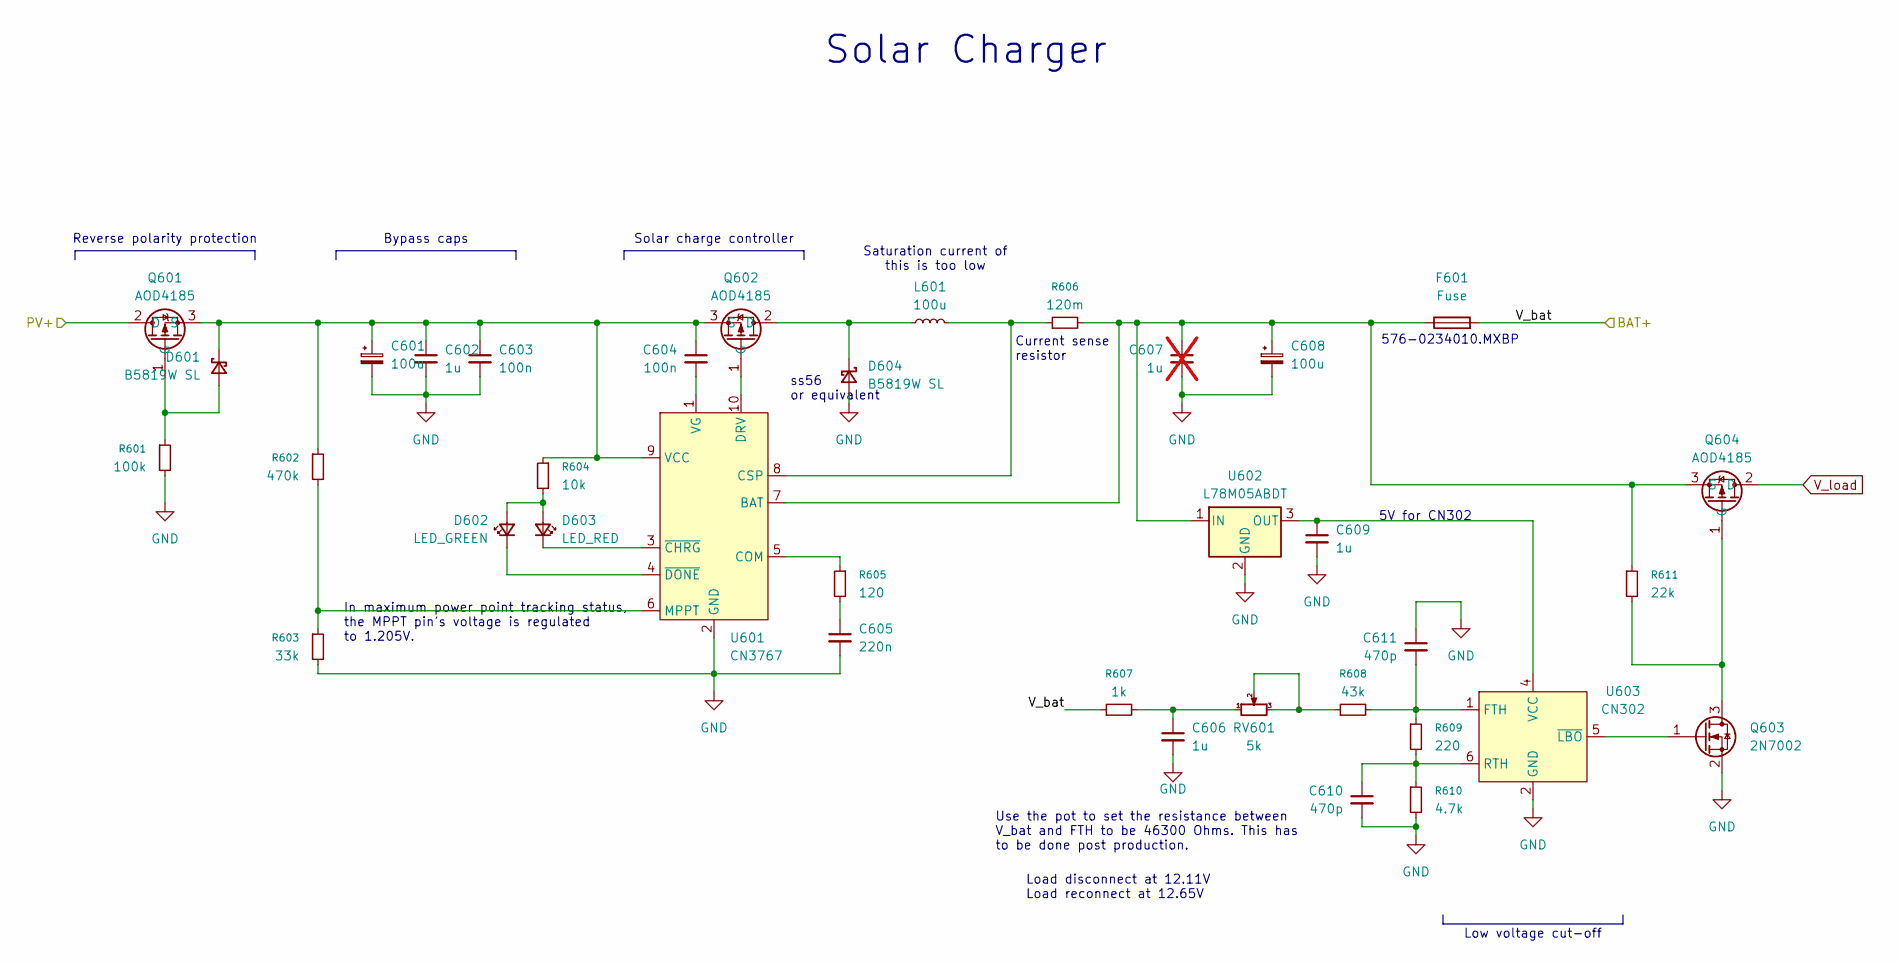
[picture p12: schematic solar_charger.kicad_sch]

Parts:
C601, C608: 100u; CP_Elec_6.3x5.9; JLCPCB Part # C72478
C602, C606, C609: 1u; C_0603_1608Metric; JLCPCB Part # C15849
C603, C604: 100n; C_0603_1608Metric; JLCPCB Part # C14663
C605: 220n; C_0603_1608Metric; JLCPCB Part # C21120
C607: 1u; C_0603_1608Metric; JLCPCB Part # C15849; not fitted
C610, C611: 470p; C_0603_1608Metric; JLCPCB Part # C1620
D601, D604: B5819W SL; D_SOD-123; JLCPCB Part # C8598
D602: LED_GREEN; LED_0805_2012Metric; JLCPCB Part # C2297
D603: LED_RED; LED_0805_2012Metric; JLCPCB Part # C84256
F601: Fuse; Fuseholder_Littelfuse_100_series_5x20mm; JLCPCB Part # C206887
L601: 100u; L_Changjiang_FNR5040S; JLCPCB Part # C167979
Q601, Q602, Q604: AOD4185; TO-252-2; JLCPCB Part # C400894
Q603: 2N7002; SOT-23; JLCPCB Part # C8545
R601: 100k; R_0603_1608Metric; JLCPCB Part # C25803
R602: 470k; R_0603_1608Metric; JLCPCB Part # C23178
R603: 33k; R_0603_1608Metric; JLCPCB Part # C4216
R604: 10k; R_0603_1608Metric; JLCPCB Part # C25804
R605: 120; R_0603_1608Metric; JLCPCB Part # C22787
R606: 120m; R_1206_3216Metric; JLCPCB Part # C24435
R607: 1k; R_0603_1608Metric; JLCPCB Part # C21190
R608: 43k; R_0603_1608Metric; JLCPCB Part # C23172
R609: 220; R_0603_1608Metric; JLCPCB Part # C22962
R610: 4.7k; R_0603_1608Metric; JLCPCB Part # C23162
R611: 22k; R_0603_1608Metric; JLCPCB Part # C31850
RV601: 5k; Potentiometer_Bourns_3386W_Horizontal; JLCPCB Part # C118907
U601: CN3767; SSOP-10_3.9x4.9mm_P1.00mm; JLCPCB Part # C81968
U602: L78M05ABDT; TO-252-2; JLCPCB Part # C58069
U603: CN302; SOT-23-6; JLCPCB Part # C32773

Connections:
/Power/Solar Charger/PV+: Q601.2 (D); also elsewhere on the board
/Power/Solar Charger/V_bat: F601.2, R607.1; also elsewhere on the board
GND: C601.2, C602.2, C603.2, C605.2, C606.2, C607.2, C608.2, C609.2, C610.2, C611.1, D604.2 (A), Q603.2 (S), R601.2, R603.2, R610.2, U601.2 (GND), U602.2 (GND), U603.2 (GND); also elsewhere on the board
unnamed: C605.1, R605.2
unnamed: C606.1, R607.2, RV601.1
unnamed: D601.2 (A), Q601.1 (G), R601.1
unnamed: C601.1, C602.1, C603.1, C604.1, D601.1 (K), Q601.3 (S), Q602.3 (S), R602.1, R604.1, U601.9 (VCC)
unnamed: D602.2 (A), D603.2 (A), R604.2
unnamed: D602.1 (K), U601.4 (~DONE)
unnamed: D603.1 (K), U601.3 (~CHRG)
unnamed: D604.1 (K), L601.1, Q602.2 (D)
unnamed: Q602.1 (G), U601.10 (DRV)
unnamed: Q603.3 (D), Q604.1 (G), R611.2
unnamed: Q603.1 (G), U603.5 (~LBO)
unnamed: C607.1, C608.1, F601.1, Q604.3 (S), R606.2, R611.1, U601.7 (BAT), U602.1 (IN)
unnamed: R608.1, RV601.2, RV601.3
unnamed: R605.1, U601.5 (COM)
unnamed: L601.2, R606.1, U601.8 (CSP)
unnamed: R602.2, R603.1, U601.6 (MPPT)
unnamed: C604.2, U601.1 (VG)
unnamed: C609.1, U602.3 (OUT), U603.4 (VCC)
unnamed: C611.2, R608.2, R609.1, U603.1 (FTH)
unnamed: C610.1, R609.2, R610.1, U603.6 (RTH)
V_load: Q604.2 (D); also elsewhere on the board

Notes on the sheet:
Current sense resistor
Low voltage cut-off
Solar Charger
Solar charge controller
Saturation current of this is too low
Reverse polarity protection
Use the pot to set the resistance between V_bat and FTH to be 46300 Ohms. This has to be done post production.
576-0234010.MXBP
In maximum power point tracking status, the MPPT pin's voltage is regulated to 1.205V.
5V for CN302
Load disconnect at 12.11V Load reconnect at 12.65V
ss56 or equivalent
Bypass caps

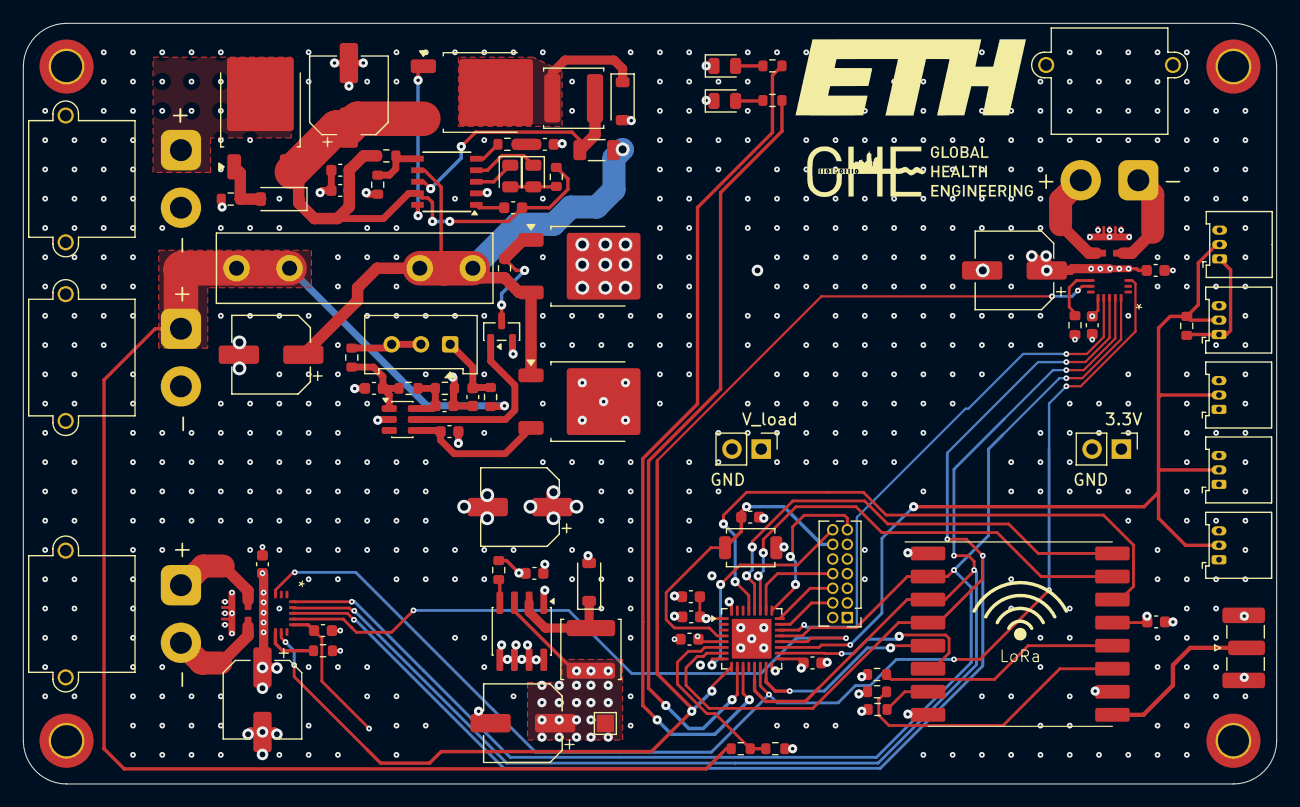
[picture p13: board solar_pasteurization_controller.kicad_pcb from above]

Board: 4 copper layers, 108.8 x 66.0 mm, 89 parts (0 on the bottom side), 61 nets.

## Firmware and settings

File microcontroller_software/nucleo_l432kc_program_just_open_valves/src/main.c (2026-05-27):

/*
 * Copyright (c) 2019 Nordic Semiconductor ASA
 *
 * SPDX-License-Identifier: Apache-2.0
 */

#include <zephyr/kernel.h>
#include <zephyr/device.h>
#include <zephyr/pm/device_runtime.h>
#include <zephyr/pm/pm.h>

#include <zephyr/drivers/gpio.h>
#include <zephyr/drivers/pwm.h>
#include <zephyr/drivers/lora.h>
#include <zephyr/drivers/counter.h>
#include <zephyr/drivers/sensor.h>
#include <zephyr/drivers/w1.h>
#include <zephyr/drivers/sensor/w1_sensor.h>
#include <zephyr/drivers/adc.h> 

#include <zephyr/sys/util.h>
#include <zephyr/sys/byteorder.h>


// Here is a description of what this program will do:
// It will mostly be asleep. Every 5 minutes it will wake up, measure the
// temperature(s), activate the valve if necessary (remember how long it
// opened that for), and send a LoRa packet with the temperature(s) and
// valve opening duration. After sending this LoRa packet, it might get
// a reply packet with new settings.




//---------------------------- DEFINES ----------------------------------------
// comment out this line to disable debug prints
#define DEBUGGING 1

// kinds of algorithms:
// 1: simple threshold-based control
// 2: ERT calculating control
#define CONTROL_ALGORITHM 1

// this defines the maximum length of a LoRa packet
#define LORA_MAX_PACKET_LEN 32

#define NUMBER_OF_TEMP_SENSORS 3

#define PWM_PHASE_FREQUENCY 250
#define PWM_TIMER_FREQUENCY 1000000

#if !DT_NODE_EXISTS(DT_PATH(zephyr_user)) || \
	!DT_NODE_HAS_PROP(DT_PATH(zephyr_user), io_channels)
#error "No suitable devicetree overlay specified"
#endif

#define DT_SPEC_AND_COMMA(node_id, prop, idx) \
	ADC_DT_SPEC_GET_BY_IDX(node_id, idx),
//------------------------ DEVICETREE INSTANCES -------------------------------

// LORA RADIO
#define LORA_NODE DT_ALIAS(lora0)
const struct device *const lora_dev = DEVICE_DT_GET(LORA_NODE);

// ONBOARD LEDs
#define LED_RED_NODE DT_ALIAS(led_red_pin)
static const struct gpio_dt_spec led_red = GPIO_DT_SPEC_GET(LED_RED_NODE, gpios);

#define LED_GREEN_NODE DT_ALIAS(led_green_pin)
static const struct gpio_dt_spec led_green = GPIO_DT_SPEC_GET(LED_GREEN_NODE, gpios);

// LORA RESET PIN
#define LORA_RESET_NODE DT_ALIAS(lora_reset_pin)
static const struct gpio_dt_spec lora_reset = GPIO_DT_SPEC_GET(LORA_RESET_NODE, gpios);

// CONSOLE UART
const struct device* const usart1_dev = DEVICE_DT_GET(DT_NODELABEL(usart1));

// COUNTER
const struct device *counter_dev = DEVICE_DT_GET(DT_NODELABEL(counter2));

// PWM
static const struct pwm_dt_spec pwm_dev = PWM_DT_SPEC_GET(DT_NODELABEL(pwmvalve));

// ADC (for battery voltage measurement)
static const struct adc_dt_spec adc_channels[] = {
	DT_FOREACH_PROP_ELEM(DT_PATH(zephyr_user), io_channels,
			     DT_SPEC_AND_COMMA)
};

// DIE TEMPERATURE
#define DIE_TEMP_NODE DT_ALIAS(die_temp0)
static const struct device *const die_temp_sensor = DEVICE_DT_GET(DIE_TEMP_NODE);

// VALVE IO
uint32_t pwm_period_in_ns = PWM_TIMER_FREQUENCY / PWM_PHASE_FREQUENCY;

//----------------------- USERSPACE VARIABLES ---------------------------------
uint8_t lora_tx_buffer[LORA_MAX_PACKET_LEN];
uint8_t lora_rx_buffer[LORA_MAX_PACKET_LEN];


// LORA config
struct lora_modem_config lora_configuration = {
	// these have to match the gateway settings!
	.frequency = 433000000,
	.bandwidth = BW_125_KHZ,
	.datarate = SF_10,
	.preamble_len = 8,
	.coding_rate = CR_4_5,
	.iq_inverted = false,
	.public_network = false,
	.tx_power = 20,
	.tx = true
};

// simple variable to hold return values
int ret;

volatile uint32_t one_second_counter = 0;
uint32_t counter_frequency;
uint16_t counter_top_value;
struct counter_alarm_cfg alarm_cfg;


// ADC variables
uint16_t adc_measurement_buffer;
struct adc_sequence sequence = {
	.buffer = &adc_measurement_buffer,
	/* buffer size in bytes, not number of samples */
	.buffer_size = sizeof(adc_measurement_buffer),
};
int32_t val_mv;
uint32_t battery_voltage_mv;

// die temperature variables
struct sensor_value die_temp;
float die_temp_celsius;

// tank temperature measurement variables
#define NUMBER_OF_TEMPERATURE_SENSORS 3
const struct device* temp_sensor_devices[NUMBER_OF_TEMPERATURE_SENSORS];
struct sensor_value temp;
struct w1_rom w1_roms[NUMBER_OF_TEMPERATURE_SENSORS];
struct sensor_value rom_values[NUMBER_OF_TEMPERATURE_SENSORS];
uint64_t rom_addresses[NUMBER_OF_TEMPERATURE_SENSORS] = {
	// TODO: THESE ARE TEMPORARY
	0x28f8a2bb00000078, // top
	0x282091c0000000eb, // middle
	0x28a91e470000006c // botttom
};
double tank_temperatures[NUMBER_OF_TEMP_SENSORS];


// control variables
#if CONTROL_ALGORITHM == 1
double tank_temperature_threshold = 70;
#endif

#if CONTROL_ALGORITHM == 2
// we need a large array of doubles to hold the ERT history
// there should be enough to look through the night?
float ert_history[128]; 
uint8_t ert_history_index = 0;
#endif



//------------------------ FUNCTION DEFINITIONS ----------------------------------

// kernel sleep forces the system to enter some power
// saving mode, use this delay instead if you don't want that
// but we do want to save power so do not use this function
static inline void blocking_sleep_ms(uint32_t ms_amount){
	uint32_t increments = ms_amount*1000*300/38;
    for(uint32_t i = 0; i < increments; i++);
}


static void counter_interrupt_callback(const struct device *dev,
                                       void *user_data) {
  // 1 second has elapsed
  one_second_counter++;
  #ifdef DEBUGGING
  //printk("Counter interrupt callback called! one_second_counter = %u\n", one_second_counter);
  #endif
}


#if CONTROL_ALGORITHM == 2
double calculate_ert(double current_temp){
	// some stuff with logarithms. The calculation is in my notebook
}
#endif

//---------------------------- MAIN FUNCTION -----------------------------------
int main(void)
{
	// CONFIGURE PERIPHERALS
	ret = pwm_set_dt(&pwm_dev, pwm_period_in_ns, 0); // turn off PWM
	gpio_pin_configure_dt(&led_red, GPIO_OUTPUT_ACTIVE);
	gpio_pin_configure_dt(&led_green, GPIO_OUTPUT_ACTIVE);
	k_msleep(1000); // wait for things to stabilize

	// DEVICE BINDINGS (TEMPERATURE SENSORS)
	temp_sensor_devices[0] =  device_get_binding("SENSOR_DS18B20_0");
	temp_sensor_devices[1] =  device_get_binding("SENSOR_DS18B20_1");
	temp_sensor_devices[2] =  device_get_binding("SENSOR_DS18B20_2");

	for(int i = 0; i < NUMBER_OF_TEMP_SENSORS; i++){
		if (!temp_sensor_devices[i] || !device_is_ready(temp_sensor_devices[i])) {
			#ifdef DEBUGGING
			printk("DS18B20 sensor device %d is not ready or found.\n", i);
			#endif
			return -1;
		}
	}

	for (int i = 0; i < NUMBER_OF_TEMP_SENSORS; i++) {
		w1_uint64_to_rom(rom_addresses[i], &w1_roms[i]);
		w1_rom_to_sensor_value(&w1_roms[i], &rom_values[i]);
	}


	// ADC SETUP
	if (!adc_is_ready_dt(&adc_channels[0])) {
		#ifdef DEBUGGING
		printk("ADC controller device %s not ready\n", adc_channels[0].dev->name);
		#endif
	}

	ret = adc_channel_setup_dt(&adc_channels[0]);
	if (ret < 0) {
		#ifdef DEBUGGING
		printk("Could not setup ADC channel (%d)\n", ret);
		#endif
	}


	while(1){
		#ifdef DEBUGGING
		printk("Program has arrived at main\n");
		#endif


		// COUNTER INIT
		one_second_counter = 0;
		counter_frequency = counter_get_frequency(counter_dev);
		
		struct counter_top_cfg counter_cfg;
		counter_cfg.ticks = counter_frequency*1; // 1 second tops
		counter_cfg.callback = counter_interrupt_callback;
		counter_cfg.flags = 0;
		counter_cfg.user_data = NULL;
		ret = counter_set_top_value(counter_dev, &counter_cfg);
		if (ret != 0) {
			#ifdef DEBUGGING
			printk("Error %d setting counter top value\n", ret);
			#endif
		}
		
		counter_start(counter_dev);
		#ifdef DEBUGGING
		printk("Counter started\n");
		#endif
		// ENDOF: COUNTER INIT


		// LED initialization
		gpio_pin_set_dt(&led_red, 1);


		// GET BATTERY VOLTAGE

		(void)adc_sequence_init_dt(&adc_channels[0], &sequence);
		ret = adc_read_dt(&adc_channels[0], &sequence);
		if (ret < 0) {
			#ifdef DEBUGGING
			printk("Could not read (%d)\n", ret);
			#endif
		}

		val_mv = (int32_t)((int16_t)adc_measurement_buffer);
		ret = adc_raw_to_millivolts_dt(&adc_channels[0],&val_mv);

		if (ret < 0) {
			#ifdef DEBUGGING
			printk(" (value in mV not available)\n");
			#endif
		} else {
			float ratio = (12200.0f / 2200.0f); // voltage divider ratio
			battery_voltage_mv = (uint32_t)((float)val_mv * ratio);
			//battery_voltage_mv = battery_voltage_mv * 13.24/13.04; // calibration factor
			#ifdef DEBUGGING
			printk("Battery voltage reading: %d mV\n", battery_voltage_mv);
			#endif
		}
		// ENDOF: GET BATTERY VOLTAGE

		// GET DIE TEMPERATURE
		ret = sensor_sample_fetch(die_temp_sensor);
		if (ret != 0) {
			#ifdef DEBUGGING
			printk("sample_fetch() failed for die temp sensor: %d\n", ret);
			k_msleep(100);
			#endif
		}

		ret = sensor_channel_get(die_temp_sensor, SENSOR_CHAN_DIE_TEMP, &die_temp);
		if (ret != 0) {
			#ifdef DEBUGGING
			printk("channel_get() failed for die temp sensor: %d\n", ret);
			k_msleep(100);
			#endif
		}
		
		die_temp_celsius = sensor_value_to_double(&die_temp);
		// print die temp
		#ifdef DEBUGGING
		printk("Die temperature: %f\n", die_temp_celsius);
		#endif

		//ENDOF: GET DIE TEMPERATURE

		// READ TEMPERATURE SENSORS
		for(int i = 0; i < NUMBER_OF_TEMP_SENSORS; i++){
			sensor_attr_set(temp_sensor_devices[i], SENSOR_CHAN_ALL,
				SENSOR_ATTR_W1_ROM, &rom_values[i]);
			ret = sensor_sample_fetch(temp_sensor_devices[i]);
			if (ret != 0) {
				#ifdef DEBUGGING
				printk("sample_fetch() failed for sensor %d: %d\n", i, ret);
				k_msleep(100);
				#endif
			}

			ret = sensor_channel_get(temp_sensor_devices[i], SENSOR_CHAN_AMBIENT_TEMP, &temp);
			if (ret != 0) {
				#ifdef DEBUGGING
				printk("channel_get() failed for sensor %d: %d\n", i, ret);
				k_msleep(100);
				#endif
			}

			tank_temperatures[i] = sensor_value_to_double(&temp);
			if(tank_temperatures[i] == 0){
				// wrong measurement. try again?
			}
			#ifdef DEBUGGING
			printk("Temp sensor %d: %f\n", i, tank_temperatures[i]);
			#endif
		}

		double tank_temperature_start = tank_temperatures[1];
		
		
		// ENDOF: READ TEMPERATURE SENSORS

		// dumbly just open the valves while we are above the voltage and temperature thresholds
		// temp threshold 50
		// voltage threshold 12.9
		//ret = pwm_set_dt(&pwm_dev, pwm_period_in_ns, pwm_period_in_ns); 
				k_msleep(500);
		while(/*battery_voltage_mv > 12400*/ die_temp_celsius < 50.0){
			#ifdef DEBUGGING
			//printk("Opening valve with modulation...\n");
			#endif
			//ret = pwm_set_dt(&pwm_dev, pwm_period_in_ns, pwm_period_in_ns*0.6); 

			// measure voltage and die temperature

			// GET DIE TEMPERATURE
			ret = sensor_sample_fetch(die_temp_sensor);
			if (ret != 0) {
				#ifdef DEBUGGING
				printk("sample_fetch() failed for die temp sensor: %d\n", ret);
				k_msleep(100);
				#endif
			}

			ret = sensor_channel_get(die_temp_sensor, SENSOR_CHAN_DIE_TEMP, &die_temp);
			if (ret != 0) {
				#ifdef DEBUGGING
				printk("channel_get() failed for die temp sensor: %d\n", ret);
				k_msleep(100);
				#endif
			}
			
			die_temp_celsius = sensor_value_to_double(&die_temp);
			// print die temp
			#ifdef DEBUGGING
			//printk("Die temperature: %f\n", die_temp_celsius);
			#endif

			// get the bottom and middle temperatures and print them
			for(int i = 0; i < NUMBER_OF_TEMP_SENSORS; i++){
				sensor_attr_set(temp_sensor_devices[i], SENSOR_CHAN_ALL,
					SENSOR_ATTR_W1_ROM, &rom_values[i]);
				ret = sensor_sample_fetch(temp_sensor_devices[i]);
				while (ret != 0) {
					#ifdef DEBUGGING
					//printk("sample_fetch() failed for sensor %d: %d\n", i, ret);
					k_msleep(100);
					#endif
					ret = sensor_sample_fetch(temp_sensor_devices[i]);
				}

				ret = sensor_channel_get(temp_sensor_devices[i], SENSOR_CHAN_AMBIENT_TEMP, &temp);
				if (ret != 0) {
					#ifdef DEBUGGING
					printk("channel_get() failed for sensor %d: %d\n", i, ret);
					k_msleep(100);
					#endif
				}

				tank_temperatures[i] = sensor_value_to_double(&temp);
				if(tank_temperatures[i] == 0){
					// wrong measurement. try again?
				}
				#ifdef DEBUGGING
				//printk("Temp sensor %d: %f\n", i, tank_temperatures[i]);
				#endif
			}
			printk("%f, %f, %f\n", tank_temperatures[0], tank_temperatures[1], tank_temperatures[2]);
			//k_msleep(1000);

		}		

		printk("Too hot or battery drained\n");
		printk("Battery voltage: %d mV, die temperature: %f C\n", battery_voltage_mv, die_temp_celsius);
		return 0;

		// CONTROL ALGORITHM

#if CONTROL_ALGORITHM == 1
		uint32_t control_loop_counter = 0; // to count how many times the valve has been opened 
		// control algorithm comes here.
		while(tank_temperatures[1] > tank_temperature_threshold && control_loop_counter < 5){ // this was 10 but then the motor drivers fried.
			// open valve until the temperature is no longer above threshold
			#ifdef DEBUGGING
			printk("Tank temperature: %f, threshold: %f \n", tank_temperatures[1], tank_temperature_threshold);
			#endif
			
			
			if(battery_voltage_mv > 13000 && die_temp_celsius < 50.0){
				// open valve for some time
				#ifdef DEBUGGING
				printk("Opening valve...\n");
				#endif
				ret = pwm_set_dt(&pwm_dev, pwm_period_in_ns, pwm_period_in_ns); 
				k_msleep(500);
				#ifdef DEBUGGING
				printk("Opening valve with modulation...\n");
				#endif
				ret = pwm_set_dt(&pwm_dev, pwm_period_in_ns, pwm_period_in_ns*0.6); 
				k_msleep(8500);
				#ifdef DEBUGGING
				printk("Closing valve...\n");
				#endif
				ret = pwm_set_dt(&pwm_dev, pwm_period_in_ns, 0); // turn off PWM
			} else {
				#ifdef DEBUGGING
				printk("Battery voltage too low to open valve: %u mV\n", battery_voltage_mv);
				#endif
				ret = pwm_set_dt(&pwm_dev, pwm_period_in_ns, 0); // turn off PWM
				break;
			}

			if (ret != 0) {
				#ifdef DEBUGGING
				printk("valve open failed: %d\n", ret);
				k_msleep(100);
				#endif
				return ret;
			}

			sensor_attr_set(temp_sensor_devices[1], SENSOR_CHAN_ALL,
				SENSOR_ATTR_W1_ROM, &rom_values[1]);
			ret = sensor_sample_fetch(temp_sensor_devices[1]);
			if (ret != 0) {
				#ifdef DEBUGGING
				printk("sample_fetch() failed for sensor %d: %d\n", 1, ret);
				k_msleep(100);
				#endif
			}

			ret = sensor_channel_get(temp_sensor_devices[1], SENSOR_CHAN_AMBIENT_TEMP, &temp);
			if (ret != 0) {
				#ifdef DEBUGGING
				printk("channel_get() failed for sensor %d: %d\n", 1, ret);
				k_msleep(100);
				#endif
			}

			tank_temperatures[1] = sensor_value_to_double(&temp);
			

			
			// measure battery voltage again
			(void)adc_sequence_init_dt(&adc_channels[0], &sequence);
			ret = adc_read_dt(&adc_channels[0], &sequence);
			if (ret < 0) {
				#ifdef DEBUGGING
				printk("Could not read (%d)\n", ret);
				#endif
			}

			val_mv = (int32_t)((int16_t)adc_measurement_buffer);
			ret = adc_raw_to_millivolts_dt(&adc_channels[0],&val_mv);

			if (ret < 0) {
				#ifdef DEBUGGING
				printk(" (value in mV not available)\n");
				#endif
			} else {
				float ratio = (12200.0f / 2200.0f); // voltage divider ratio
				battery_voltage_mv = (uint32_t)((float)val_mv * ratio);
				#ifdef DEBUGGING
				printk("Battery voltage reading: %d mV\n", battery_voltage_mv);
				#endif
			}


			
		

			control_loop_counter++; // to mark how many times the loop has run
			k_msleep(1000);
		}

		if(ret != 0){ // something is wrong if we reach here. Maybe the valves are not opening
			// we exited the control loop because we reached the maximum number of iterations
			// put an error code in the lora packet
			memset(lora_tx_buffer, 0xFF, 20); // the lora packet will be 20 bytes long in any case
		} else {
			// we exited the control loop normally, or never entered it

			uint32_t tank_temp_start_mcelsius = (uint32_t)(tank_temperature_start*1000);
			uint32_t tank_temp_end_mcelsius = (uint32_t)(tank_temperatures[1]*1000);
			uint32_t tank_temp_bottom_mcelsius = (uint32_t)(tank_temperatures[2]*1000);
			uint32_t tank_temp_top_mcelsius = (uint32_t)(tank_temperatures[0]*1000);
			uint32_t die_temp_mcelsius = (uint32_t)(die_temp_celsius*1000);

			// the data we will put in the lora packet consists of:
			// 4 bytes: battery voltage in mv
			// 4 bytes: tank temperature at the top in mC
			// 4 bytes: tank temperature at the middle in the beginning in mC
			// 4 bytes: tank temperature at the bottom in mC
			// // 4 bytes: number of times the valve was opened (uint32_t)
			// 4 bytes: tank temperature at the middle in the end in mC
			memcpy(&lora_tx_buffer[0], &battery_voltage_mv, 4);
			memcpy(&lora_tx_buffer[4], &tank_temp_top_mcelsius, 4);
			memcpy(&lora_tx_buffer[8], &tank_temp_start_mcelsius, 4);
			memcpy(&lora_tx_buffer[12], &tank_temp_bottom_mcelsius, 4);
			memcpy(&lora_tx_buffer[16], &tank_temp_end_mcelsius, 4);
			memcpy(&lora_tx_buffer[20], &die_temp_mcelsius, 4);
			//memcpy(&lora_tx_buffer[24], &tank_temp_bottom_mcelsius, 4);
			//memcpy(&lora_tx_buffer[28], &tank_temp_top_mcelsius, 4);

		}
		
		// LORA RADIO CONFIGURATION AND SEND PACKET
		// write lora config
		//gpio_pin_set_dt(&lora_en, 1);

		gpio_pin_set_dt(&lora_reset, 1);
		k_msleep(500);
		gpio_pin_set_dt(&lora_reset, 0);
		k_msleep(1500);

		gpio_pin_set_dt(&led_green, 1);

		ret = lora_config(lora_dev, &lora_configuration);
		if (ret < 0) {
			#ifdef DEBUGGING
			printk("LoRa configuration failed with error %d\n", ret);
			#endif
		}

		k_msleep(100);

		ret = lora_send(lora_dev, lora_tx_buffer, 24);
		if (ret == 0) {
		#ifdef DEBUGGING
			printk("LoRa send sucessful\n");
			k_msleep(100);
			#endif
		}
		if (ret < 0) {
			#ifdef DEBUGGING
			printk("LoRa send failed\n");
			k_msleep(100);
			#endif
		}

#endif


		// put to sleep
		#ifdef DEBUGGING
		printk("Entering sleep mode...\n");
		#endif
		// Enter deep sleep mode
		gpio_pin_set_dt(&led_green, 0);
		gpio_pin_set_dt(&led_red, 0);
		//gpio_pin_set_dt(&lora_en, 0);

		uint32_t current_ticks;
		counter_get_value(counter_dev, &current_ticks);

		counter_stop(counter_dev);
		
		k_msleep(1000*60*5 - current_ticks/10 - one_second_counter*1000); // sleep for 5 minutes
		//k_msleep(1000);
	}	

	return 0;
}

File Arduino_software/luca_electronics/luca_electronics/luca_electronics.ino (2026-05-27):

#include <OneWire.h>
#include <DallasTemperature.h>

#define GAS_HEATER_TURN_ON_THRESHOLD 50.0

// DS18B20 ROMs (hard-coded)
// 2881774700000099
// 28BF1147000000EA

byte sensor0ROM[8] = { 0x28, 0x8D, 0x2A, 0x55, 0x00, 0x00, 0x00, 0xA2 }; // is at the bottom
byte sensor1ROM[8] = { 0x28, 0xBF, 0x11, 0x47, 0x00, 0x00, 0x00, 0xEA }; // is at the top

// PIN definitions
const int PUMP_OUT_PIN = 2;
const int TEMP_SENSOR_PIN = 3;
const int VALVE_EN = 9; // 32kHz PWM
const int VALVE_1_EN2 = 7;
const int VALVE_1_EN4 = 8;
const int VALVE_2_EN2 = 4;
const int VALVE_2_EN4 = 5;

bool valveState = 0;
bool pumpState = 0;

// OneWire + DallasTemperature
OneWire oneWire(TEMP_SENSOR_PIN);

DallasTemperature sensors(&oneWire);

DeviceAddress deviceAddress; // variable to store the device address

float temp0 = 0.0;
float temp1 = 0.0;


// Valve control helpers
void openValve(int valveNumber) {
  switch (valveNumber) {
    case 1:
      digitalWrite(VALVE_1_EN2, HIGH);
      digitalWrite(VALVE_1_EN4, LOW);
      break;
    case 2:
      digitalWrite(VALVE_2_EN2, HIGH);
      digitalWrite(VALVE_2_EN4, LOW);
      break;
  }
}

void closeValve(int valveNumber) {
  switch (valveNumber) {
    case 1:
      digitalWrite(VALVE_1_EN2, LOW);
      digitalWrite(VALVE_1_EN4, HIGH);
      break;
    case 2:
      digitalWrite(VALVE_2_EN2, LOW);
      digitalWrite(VALVE_2_EN4, HIGH);
      break;
  }
}

void stopValve(int valveNumber) {
  switch (valveNumber) {
    case 1:
      digitalWrite(VALVE_1_EN2, LOW);
      digitalWrite(VALVE_1_EN4, LOW);
      break;
    case 2:
      digitalWrite(VALVE_2_EN2, LOW);
      digitalWrite(VALVE_2_EN4, LOW);
      break;
  }
}

float readTempSafe(DallasTemperature &sensor) {
  float t;
  do {
    sensor.requestTemperatures();
    //delay(1000);
    t = sensor.getTempCByIndex(0);
    Serial.print("Measured temperature: ");
    Serial.println(t);
    
  } while (t == DEVICE_DISCONNECTED_C || t == 85.0);
  return t;
}


void setup() {
  // 32kHz PWM on Timer1
  //TCCR1A = (1 << WGM10) | (1 << COM1A1);
  //TCCR1B = (1 << WGM12) | (1 << CS10);

  pinMode(PUMP_OUT_PIN, OUTPUT);
  pinMode(VALVE_1_EN2, OUTPUT);
  pinMode(VALVE_1_EN4, OUTPUT);
  pinMode(VALVE_EN, OUTPUT);
  pinMode(VALVE_2_EN2, OUTPUT);
  pinMode(VALVE_2_EN4, OUTPUT);

  analogWrite(VALVE_EN, 128); // 50% duty

  Serial.begin(115200);

  sensors.begin();

  openValve(1);
  openValve(2);

  stopValve(1);
  stopValve(2);
}




void loop() {

  
  do {
    sensors.requestTemperatures();
    temp1 = sensors.getTempC(sensor1ROM);
    //temp1 = sensors1.getTempCByIndex(0);
//    Serial.println("failure 1");
    delay(100);
  } while (temp1 == DEVICE_DISCONNECTED_C || temp1 == 85.0);

  //Serial.println(temp1);

  do {
    sensors.requestTemperatures();
    temp0 = sensors.getTempC(sensor0ROM);
    //temp1 = sensors1.getTempCByIndex(0);
    //Serial.println("failure 0");
    delay(100);
  } while (temp0 == DEVICE_DISCONNECTED_C || temp0 == 85.0);

  
  
  if((temp0 > GAS_HEATER_TURN_ON_THRESHOLD) | (abs(temp0 - temp1) > 5.0))
    digitalWrite(PUMP_OUT_PIN, HIGH);
  else
    digitalWrite(PUMP_OUT_PIN, LOW);

  Serial.print("lj ");
  Serial.print("valveState ");
  Serial.print(valveState);
  Serial.print(" pumpState ");
  Serial.print(pumpState);
  Serial.print(" temps ");
  Serial.print(temp0);
  Serial.print(" ");
  Serial.println(temp1);

  delay(2300);
}


void printAddress(DeviceAddress deviceAddress) {
  for (uint8_t i = 0; i < 8; i++) {
    Serial.print("0x");
    if (deviceAddress[i] < 0x10) {
      Serial.print("0");
    }
    Serial.print(deviceAddress[i], HEX);
    if (i < 7) {
      Serial.print(", ");
    }
  }
  Serial.println();
}


/*
#include <OneWire.h>
#include <DallasTemperature.h>

// DS18B20 ROMs (hard-coded)
// 2881774700000099
// 28BF1147000000EA

byte sensor0ROM[8] = { 0x28, 0x8D, 0x2A, 0x55, 0x00, 0x00, 0x00, 0xA2 }; // is at the bottom
byte sensor1ROM[8] = { 0x28, 0xBF, 0x11, 0x47, 0x00, 0x00, 0x00, 0xEA }; // is at the top

// PIN definitions
const int PUMP_OUT_PIN = 2;
const int TEMP_SENSOR_PIN_0 = 10;
const int TEMP_SENSOR_PIN_1 = 3;
const int VALVE_EN = 9; // 32kHz PWM
const int VALVE_1_EN2 = 7;
const int VALVE_1_EN4 = 8;
const int VALVE_2_EN2 = 4;
const int VALVE_2_EN4 = 5;

bool valveState = 0;
bool pumpState = 0;

// OneWire + DallasTemperature
OneWire oneWire0(TEMP_SENSOR_PIN_0);
OneWire oneWire1(TEMP_SENSOR_PIN_1);

DallasTemperature sensors0(&oneWire0);
DallasTemperature sensors1(&oneWire1);

DeviceAddress deviceAddress; // variable to store the device address

float temp0 = 0.0;
float temp1 = 0.0;


// Valve control helpers
void openValve(int valveNumber) {
  switch (valveNumber) {
    case 1:
      digitalWrite(VALVE_1_EN2, HIGH);
      digitalWrite(VALVE_1_EN4, LOW);
      break;
    case 2:
      digitalWrite(VALVE_2_EN2, HIGH);
      digitalWrite(VALVE_2_EN4, LOW);
      break;
  }
}

void closeValve(int valveNumber) {
  switch (valveNumber) {
    case 1:
      digitalWrite(VALVE_1_EN2, LOW);
      digitalWrite(VALVE_1_EN4, HIGH);
      break;
    case 2:
      digitalWrite(VALVE_2_EN2, LOW);
      digitalWrite(VALVE_2_EN4, HIGH);
      break;
  }
}

void stopValve(int valveNumber) {
  switch (valveNumber) {
    case 1:
      digitalWrite(VALVE_1_EN2, LOW);
      digitalWrite(VALVE_1_EN4, LOW);
      break;
    case 2:
      digitalWrite(VALVE_2_EN2, LOW);
      digitalWrite(VALVE_2_EN4, LOW);
      break;
  }
}

float readTempSafe(DallasTemperature &sensor) {
  float t;
  do {
    sensor.requestTemperatures();
    //delay(1000);
    t = sensor.getTempCByIndex(0);
    Serial.print("Measured temperature: ");
    Serial.println(t);
    
  } while (t == DEVICE_DISCONNECTED_C || t == 85.0);
  return t;
}


void setup() {
  // 32kHz PWM on Timer1
  //TCCR1A = (1 << WGM10) | (1 << COM1A1);
  //TCCR1B = (1 << WGM12) | (1 << CS10);

  pinMode(PUMP_OUT_PIN, OUTPUT);
  pinMode(VALVE_1_EN2, OUTPUT);
  pinMode(VALVE_1_EN4, OUTPUT);
  pinMode(VALVE_EN, OUTPUT);
  pinMode(VALVE_2_EN2, OUTPUT);
  pinMode(VALVE_2_EN4, OUTPUT);

  analogWrite(VALVE_EN, 128); // 50% duty

  Serial.begin(115200);

  sensors0.begin();
  delay(10);
  sensors1.begin();
  delay(10);


}



void loop() {
  digitalWrite(PUMP_OUT_PIN, LOW);

  do {
    sensors1.requestTemperatures();
    temp1 = sensors1.getTempC(sensor1ROM);
    //temp1 = sensors1.getTempCByIndex(0);
    Serial.print("temperature 1: ");
    Serial.println(temp1);
  } while (temp1 == DEVICE_DISCONNECTED_C || temp1 == 85.0);
  
  do {
    sensors0.requestTemperatures();
    temp0 = sensors0.getTempC(sensor0ROM);
    Serial.print("temperature 0: ");
    Serial.println(temp0);
    
  } while (temp0 == DEVICE_DISCONNECTED_C || temp0 == 85.0);

  

  

  
  
  
  // temporary for testing
  

  Serial.print("lj ");
  Serial.print("valveState ");
  Serial.print(valveState);
  Serial.print(" pumpState ");
  Serial.print(pumpState);
  Serial.print(" temps ");
  Serial.print(temp0);
  Serial.print(" ");
  Serial.println(temp1);

  delay(2300);
}
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

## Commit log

2026-03-05 initial push with the data until now
    [edb_data_2026-02-20.csv, edb_data_2026-02-21.csv, edb_data_2026-02-22.csv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]
2026-03-07 Periodic CSV update
    [edb_data_2026-03-05.csv, edb_data_2026-03-06.csv, edb_data_2026-03-07.csv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]
2026-05-27 transfered private git repo files to the ghe repo
    [Fuse Holder PCB.STEP, User Library-HSOP_20pin_IC-MC33886PVW.step, User Library-XT30PW-M.step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]
